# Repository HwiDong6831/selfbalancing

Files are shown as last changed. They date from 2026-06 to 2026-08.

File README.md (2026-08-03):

# 삼각형 셀프밸런싱 로봇

1축 밸런싱 휠을 통해 스스로 중심을 잡는 삼각형 로봇.

### 특징
외부 충격에 실시간으로 대응하여 균형을 유지.

가속도 센서를 3개 탑재하여, 센싱된 정보를 다수결로 결정하여 판단하도록 설계.

동작 영상 : https://www.youtube.com/shorts/YMNRPPPrXEo

## 목차

**계획 · 스펙**

1. [요구사항](#1-요구사항)
   - [기능 요구사항](#기능-요구사항)
   - [센서 결함 시뮬레이션 및 검증 계획](#센서-결함-시뮬레이션-및-검증-계획)
   - [디지털 트윈](#디지털-트윈)
2. [언어 / 빌드 환경](#2-언어--빌드-환경)
3. [라이브러리](#3-라이브러리)
4. [주요 부품](#4-주요-부품)

**구현**

5. [로봇 형상](#5-로봇-형상)
6. [서버 / 대시보드](#6-서버--대시보드)

## 1. 요구사항
### 기능 요구사항
- FR-1(센싱) : MPU6500 3개를 이용해 실시간으로 자세 정보를 측정해야 한다.
- FR-2(결함 허용) : Voting 알고리즘을 구현한다. 3개의 센서 데이터를 비교해 이상치를 배제한다.
- FR-3(균형 유지) : 정상 센서 데이터를 이용해 자세 정보를 계산하고, 상태피드백 제어(각도·각속도·휠속도)를 통해 로봇이 균형을 유지해야 한다.
- FR-4(모터 제어) : BLDC 모터를 FOC 방식으로 제어해야 한다.
- FR-5(모터 피드백) : MT6701을 ABZ 증분 방식으로 읽어 모터 정보를 실시간으로 측정해야 한다.
- FR-6(무선 통신) : Wi-Fi를 이용하여 센서 데이터를 확인하거나 로봇을 제어할 수 있어야 한다.
- FR-7(안정성) : 외부 충격이 발생하더라도 균형을 회복해야 한다.
- FR-8(디지털 트윈) : 모바일 웹에서 로봇의 현재 자세를 실시간 3D로 확인할 수 있어야 한다.

### 센서 결함 시뮬레이션 및 검증 계획

실제 하드웨어 고장을 기다리지 않고, 센서 데이터를 인위적으로 변조하여 결함 상황을 재현한다.

모바일에서 Wi-Fi 기반 제어로 구현한다.

1. 센싱 정보 누락

    특성 센서의 값을 무효 처리 한다.

    (하드웨어 고장, 통신 끊어짐 상황 묘사)

2. 값 고정 오류

    특정 센서의 값이 고정된 값이나, 마지막 정상 값을 유지되도록 한다.

    (register lock, 센서 freeze 상황 묘사)

3. 점진적 변형

    특성 센서의 값이 지속적으로 변형되도록 한다.

    (센서 열화, IMU drift 상황 묘사)

4. 다중 장애

    2개 센서에 1~3번 현상이 나타나도록 한다.

    (단일 센서 모드로 동작하는 상황 묘사)

### 디지털 트윈

모바일 웹에서 로봇의 현재 자세를 실시간 3D로 확인한다.

- 자세 소스: voting 통과 융합 기울기 + 엔코더 휠 각도.
- 표현: 기울기 1축과 휠 회전. 반작용휠 로봇이라 둘 다 같은 축으로 돌아, 휠을 몸통의 자식으로 두면 그대로 맞아떨어진다.
- 통신: WebSocket. ESP32 → Spring 서버 → 브라우저 중계.
- 렌더: 대시보드와 같은 Spring 서버가 호스팅(Three.js), 기존 프레임 `.obj` 를 `.glb` 로 변환해 사용.

상세: [docs/digital-twin.md](./docs/digital-twin.md)

## 2. 언어 / 빌드 환경

### 로봇 (ESP32)

| 항목 | 내용 |
|---|---|
| 언어 | C |
| 프레임워크 | ESP-IDF v5.5.4 |
| 빌드 | idf.py (CMake) |
| 타겟 보드 | ESP32 D1 Mini Live |

### 서버 / 대시보드

| 항목 | 내용 |
|---|---|
| 언어 | Java 21 |
| 프레임워크 | Spring Boot 4.1.0 (webmvc + websocket) |
| 빌드 | Gradle |
| 프론트 | HTML/CSS/JS, Three.js |

## 3. 라이브러리

| 기능 | 구현 |
|---|---|
| FOC 모터제어 | 직접 구현 — `esp/components/foc/` |
| 자기인코더(MT6701) | 직접 구현 — ESP32 PCNT로 ABZ 펄스 카운트, `esp/components/encoder/` |
| 가속도센서(MPU6500) | 직접 구현 — 멀티플렉서 경유 3채널, `esp/components/mpu6050/` |
| WebSocket 클라이언트 | `espressif/esp_websocket_client` |

## 4. 주요 부품
메인보드: ESP32 D1 Mini Live

FOC 드라이버: SimpleFOC Mini

멀티플렉서: PCA9548A

가속도센서: MPU6500

자기인코더: MT6701

모터: 2804-100KV 브러시리스

## 5. 로봇 형상

<table>
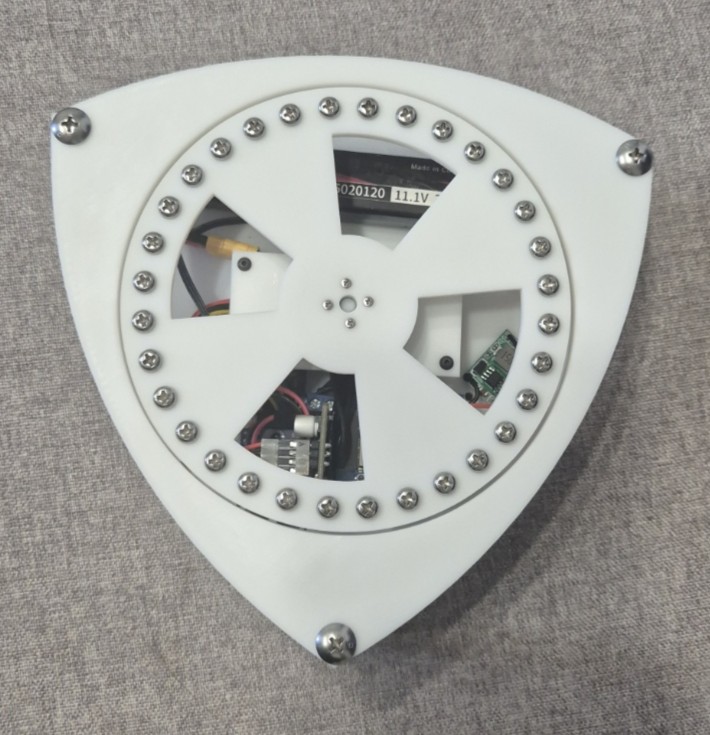
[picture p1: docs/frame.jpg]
로봇 형상 — 외부
  <tr><td></td></tr>
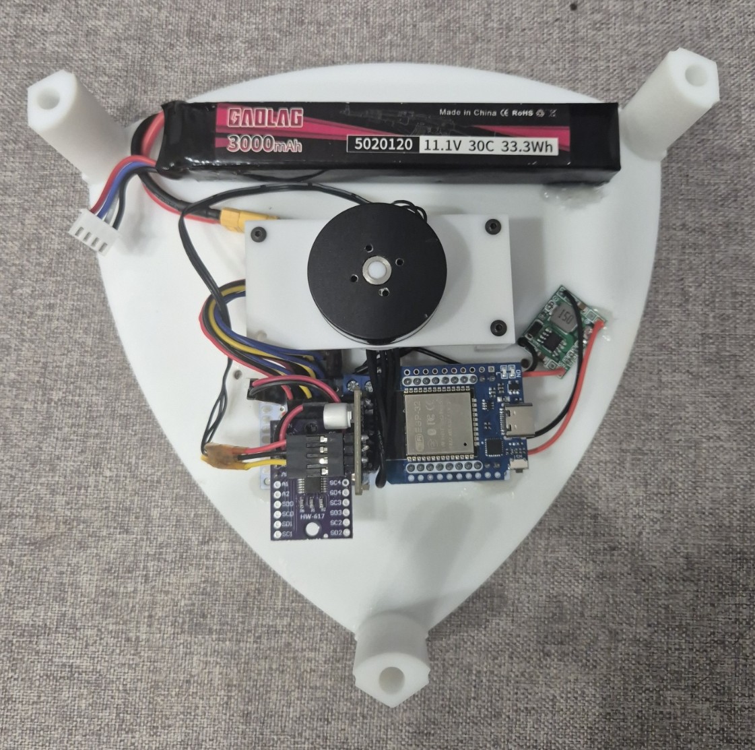
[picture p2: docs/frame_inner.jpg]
로봇 형상 — 내부
  <tr><td></td></tr>
</table>

## 6. 서버 / 대시보드

ESP32가 측정한 값을 브라우저에서 실시간으로 확인한다. ESP32를 웹서버로 쓰지 않고 **Spring 서버가 중계**한다.

```
ESP32 ──WS──► Spring 서버 ──WS──► 브라우저
              (중계 + 정적 호스팅)
```

대시보드 표시 항목:

- 밸런싱 상태 (기울기, 각속도, 기준 각도, q축 전압, 휠 각도)
- 센서 3개의 6축 값과 채널별 영점
- Voting 판정 — 가속도·자이로 각각의 채택/배제 채널
- 이상 이력 — 배제된 센서의 값, 채택 평균, 벌어진 폭을 표로 기록
- 3D 자세 — 실물 모델로 현재 기울기와 휠 회전을 실시간 표시
- ESP32 시리얼 로그 미러링

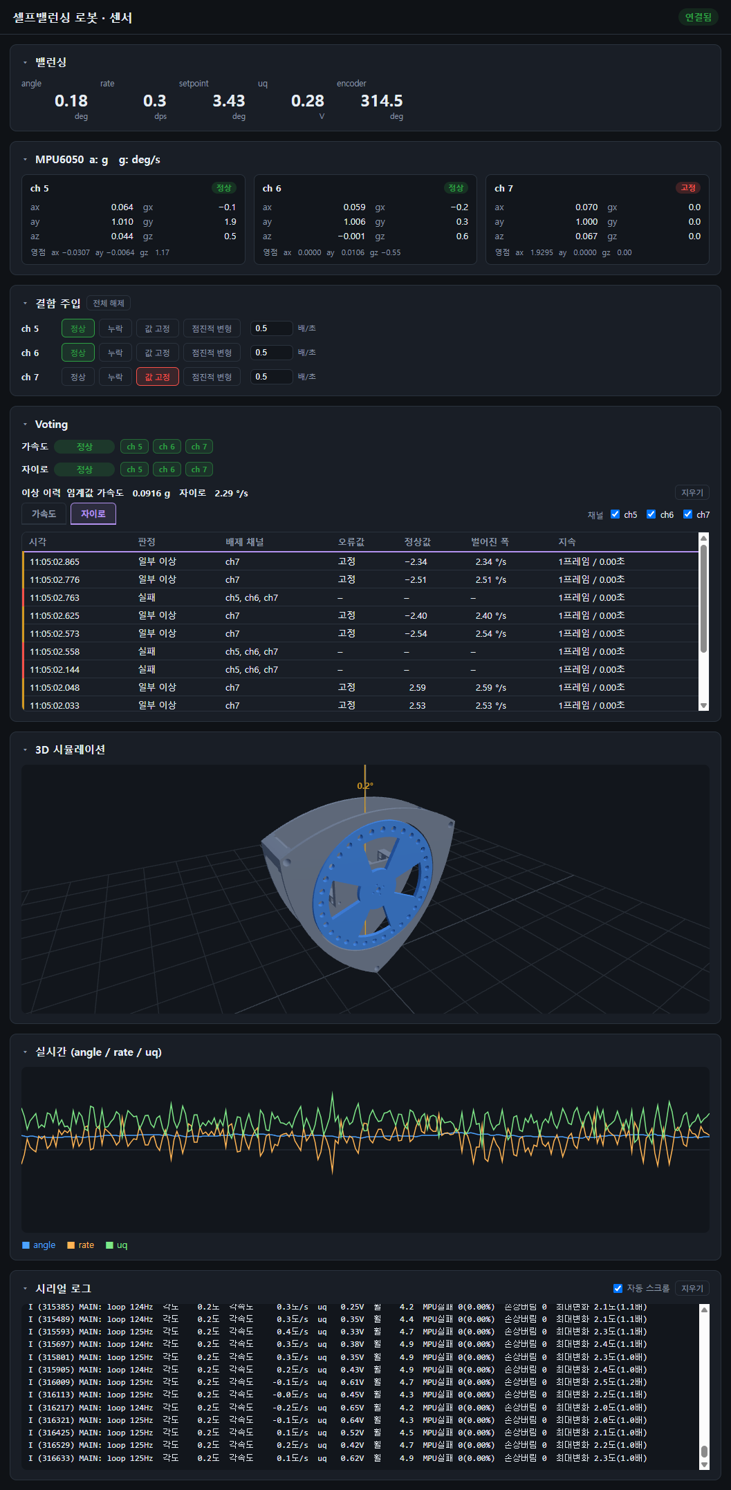
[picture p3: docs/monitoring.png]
대시보드


상세: [docs/server.md](./docs/server.md)

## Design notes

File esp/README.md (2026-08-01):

# esp — 밸런싱 로봇 펌웨어 (ESP-IDF v5.5)

ESP32 D1 Mini 에서 도는 제어 펌웨어. core 0 이 제어 루프, core 1 이 통신을 맡는다.

## 구조

```
main/           app_main. 초기화 → 캘리브레이션 → 1kHz 제어 루프
components/
  mpu6050/      MPU6500 ×3 (PCA9548A mux 0x70)
  encoder/      MT6701 자기 인코더 (0x06)
  foc/          전압모드 FOC (LEDC 3-PWM + EN)
  balance/      상보필터 각도 추정 + 토크모드 상태피드백
  telemetry/    WiFi STA + WebSocket 송신 + ESP_LOGx 미러링
```

## 빌드

`export.ps1` 이 py3.14 가상환경을 찾는데 실제 설치된 건 py3.11 이라 경로를 먼저 지정해야 한다.

```powershell
$env:IDF_PYTHON_ENV_PATH="C:\Espressif\python_env\idf5.5_py3.11_env"
. C:\Espressif\frameworks\esp-idf-v5.5.4\export.ps1

idf.py build
idf.py -p COM<n> flash monitor
```

WiFi/서버 주소는 커밋되지 않는다.
아래 명령어로 secrets.h 파일을 생성한 후, 내부에 로봇을 연결할 WiFi 및 서버 정보를 기입한다.
```
cp main/secrets.h.example main/secrets.h
```

## 주의

- 튜닝 중 통신을 완전히 배제하려면 `main.c` 의 `TELEMETRY_ENABLED` 를 0 으로 변경한다.

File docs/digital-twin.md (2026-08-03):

# 디지털 트윈

모바일 웹에서 로봇의 현재 자세를 실시간 3D로 확인하는 기능.

## 1. 목적

- 실제 기기의 자세를 모바일 화면의 3D 모델에 실시간 반영한다.
- 센서 결함 시뮬레이션 시 자세 변화를 시각적으로 검증하는 도구로 사용한다.
- 기존 모바일 Wi-Fi 제어 기능(FR-6)과 동일한 웹 UI에 통합한다.

## 2. 자세 데이터

### 자세 소스

- Voting 알고리즘을 통과한 융합 기울기.
- 엔코더가 읽은 휠 각도.

### 표현 방식 — 1축 기울기와 휠 회전

**측정 가능한 자유도가 1개다.** 물체가 향한 방향은 축 3개로 정해지는데, 중력은 "아래가 어디인가" 만 알려주므로 그중 둘까지만 고정된다. 나머지 하나(제자리 돌기)를 알려면 지자기 센서가 필요한데 이 로봇에는 없다. 자이로를 적분하면 몇 분 만에 오차가 쌓여 화면이 제멋대로 돌아간다.

그래서 쿼터니언을 쓰지 않는다. 쿼터니언은 세 축을 다 알 때 의미가 있고, 여기서는 채울 수 없는 성분을 지어내는 셈이 된다. 대신 **실제로 측정되는 기울기 1축과 휠 회전**을 보낸다.

반작용휠 로봇은 몸이 기우는 축과 휠이 도는 축이 같다. 그래서 3D 에서 휠을 몸통의 자식으로 두면 기울기는 휠이 저절로 따라오고, 휠 회전만 따로 주면 된다.

### 페이로드

- 기울기 `angle`, 휠 각도 `encoder.angle`. 텔레메트리 프레임에 이미 들어 있어 별도 필드가 필요 없다.
- 송신 주기: 50Hz.

## 3. 통신

- 프로토콜: **WebSocket** (저지연 연속 스트림, HTTP 폴링 대비 적합).
- 경로: **ESP32 → Spring 서버 → 브라우저**. ESP32 는 서버가 아니라 클라이언트다.
- 기존 모바일 제어 채널과 동일한 Wi-Fi 연결 재사용.

> 처음에는 ESP32 가 직접 WebSocket 서버가 되는 안이었으나, ESP32 부담과 동시 접속 수
> 때문에 Spring 서버가 중계하는 구조로 바꿨다. 근거는 [server.md](./server.md) 3장.

## 4. 모바일 3D 렌더

- 웹 기반 렌더링: **Three.js / WebGL**. 앱 설치 불필요.
- 웹 자산 호스팅: **대시보드와 같은 Spring 서버**. ESP32 온보드 flash 미사용.
- 3D 모델: 기존 프레임 export 재사용. `Assembly.obj`(몸통)와 `wheel.obj`(휠)를 각각 `.glb` 로 변환해 쓴다 — 둘이 따로 있어야 휠만 돌릴 수 있다.
- 몸통 그룹을 기울기만큼, 그 자식인 휠을 엔코더 각도만큼 회전시킨다.

## 5. 결함 시뮬레이션 연동

- 트윈 화면에 센서 상태 오버레이: 어느 센서가 faulted 인지, voting 결과 표시.
- 결함 주입 시 자세 흔들림을 3D로 시각 확인 → 검증 도구 역할.

## 6. 구성요소

| 계층 | 구성요소 |
|---|---|
| ESP32 | WebSocket 클라이언트 (`espressif/esp_websocket_client`) |
| 자세 소스 | voting 통과 융합 기울기 + 엔코더 휠 각도 |
| 서버 | Spring Boot — 중계 + 웹 자산(HTML/JS) 호스팅 |
| 모바일 웹 | Three.js 3D 렌더, WebSocket 클라이언트 |
| 3D 모델 | 프레임 export 를 변환한 `.glb` (몸통 / 휠) |

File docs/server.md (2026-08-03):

# 센서 웹 서버 구조와 선택 근거

로봇의 센서 정보를 웹 페이지에서 실시간으로 보기 위한 별도 서버(`server/`)의 설계 결정을 정리한다. **무엇을 했는지보다 왜 그렇게 했는지**에 초점을 둔다.

## 1. 목적

- ESP32가 측정한 센서/제어 상태를 브라우저에 실시간 스트리밍한다.
- 결함 시뮬레이션(FR-2)·디지털 트윈(FR-8)의 공통 표시 기반으로 쓴다.
- 현재 단계: **ESP32 연동 전에 서버·웹을 먼저 완성**하고, 가짜 데이터로 검증한다.

## 2. 스택

| 항목 | 선택 |
|---|---|
| 언어/런타임 | Java 21 (Temurin) |
| 프레임워크 | Spring Boot 4.1.0 (webmvc + websocket) |
| 빌드 | Gradle |
| 직렬화 | Jackson 3 (`tools.jackson`, Spring Boot 4 기본) |
| 프론트 | 순수 HTML/CSS/JS, 정적 호스팅 (라이브러리 무의존) |

## 3. 아키텍처 선택 — Spring 허브

```
ESP32 ──WS──► Spring 서버 ──WS──► 브라우저
                    (중계 + 정적 호스팅)
```

두 가지 후보가 있었다.

- **(A) Spring 허브 (채택):** ESP32가 Spring으로 데이터를 보내고, Spring이 브라우저로 중계 + 웹 자산 호스팅.
- **(B) ESP32 직결:** ESP32가 직접 WebSocket 서버가 되고 브라우저가 붙음 (초기 `digital-twin.md` 안).

**(A)를 택한 이유:**

- ESP32 부담을 줄인다. 온보드 flash에 웹 자산을 안 올려도 되고, 동시 접속 수 제한(임베디드 WS 서버)에서 자유롭다.
- 다중 브라우저(PC + 모바일 동시)를 서버가 fan-out으로 감당한다.
- 로깅·기록·결함 주입 제어 등 확장 지점을 서버에 둘 수 있다.
- Spring Boot 스캐폴드에 이미 websocket starter가 포함돼 있어 자연스럽다.

## 4. 핵심 설계 — `TelemetrySink` 경계(seam)

데이터를 **만드는 쪽**과 **뿌리는 쪽**을 인터페이스 하나로 갈라 놓았다.

```java
public interface TelemetrySink {
    void publish(SensorFrame frame);
}
```

- **생산자**(현재 `DummyTelemetrySource`)는 이 인터페이스에만 의존한다. 뒤에서 WebSocket으로 어떻게 전송되는지 전혀 모른다.
- **구현체**(`DashboardWebSocketHandler`)가 받은 프레임을 접속한 모든 브라우저로 broadcast 한다.

**이 벽을 세운 이유 — 생산자 교체 비용을 0으로 만들기 위해서.** 지금은 더미가 `publish`를 부르고, ESP32 연동 시엔 ingest 핸들러가 같은 `publish`를 부른다. 그 사이 **전송·스키마·프론트 코드는 한 줄도 바뀌지 않는다**.

## 5. 데이터 계약 — `SensorFrame`

서버↔브라우저가 합의하는 JSON 한 프레임의 모양을 `record` 하나로 고정했다.

- `ts`, `sensors[3]`(MPU 6축 + fault), `voting`(used/rejected), `balance`(angle/rate/setpoint/uq), `encoder`.
- `balance` 필드는 펌웨어 `main.c` 변수와 1:1 대응.
- **계약을 한 곳에 못박은 이유:** 생산자·소비자·프론트가 각자 이 record 하나만 보고 맞추면 되므로, 필드 변경 시 파급 지점이 명확하다.

## 6. 더미 우선(mock-first) 전략

- `DummyTelemetrySource`가 `@Scheduled(fixedRate=33)`로 ≈30Hz 프레임을 생성해 `publish`.
- 값은 −10~10 **삼각파** 하나(`v`)를 모든 필드에 채우는 단순 형태. *실제처럼 보일 필요가 없으므로* 사인파·노이즈·센서 스케일 흉내를 걷어내고 최소화했다.
- `@ConditionalOnProperty(telemetry.mock.enabled)`로 켜고 끈다. **ESP32 연동 시 `false`로 두면 더미 빈이 아예 생성되지 않는다** — 코드 삭제 불필요.

**mock-first 이유:** 무선 펌웨어가 나오기 전에 서버·웹 전체 경로를 먼저 눈으로 검증하기 위해서.

## 7. 통신 — WebSocket + 순수 fan-out

- 프로토콜: **WebSocket** (저지연 연속 스트림, HTTP 폴링 대비 적합).
- 엔드포인트: `/ws/telemetry`.
- STOMP 같은 pub/sub 계층 없이 **순수 `TextMessage` fan-out**을 택했다. 채널이 하나(텔레메트리 단방향 브로드캐스트)뿐이라 STOMP는 오버킬.

## 8. 프론트엔드 — 무의존 정적 웹

- Spring이 `static/`을 자동 서빙. 앱 설치 불필요, 모바일 접속 가능.
- 차트는 외부 라이브러리 없이 `<canvas>`에 직접 그린다(최근 240프레임 링버퍼). CSP·오프라인·파일 수 측면에서 유리.
- 데이터 수신(30Hz)과 화면 렌더(`requestAnimationFrame`)를 분리해 부드럽게 그린다.
- 숫자 표시는 고정폭 + 부호 자리 확보(음수 `−`, 양수 figure space)로 값이 바뀌어도 흔들리지 않게 했다.

## 9. 동시성(스레드) 결정

서버는 멀티스레드다. 스케줄러 스레드(더미 생산)와 톰캣 연결 스레드(브라우저 접속/해제)가 공유 상태를 건드린다. 판단 기준은 **"이 데이터를 건드리는 스레드가 2명 이상인가"**.

| 대상 | 스레드 수 | 처리 | 이유 |
|---|---|---|---|
| `sessions` 집합 | 스케줄러 + 톰캣 다수 | `CopyOnWriteArraySet` | 순회(30Hz)가 잦고 변경(접속)이 드문 비대칭. 순회 중 변경돼도 예외·손상 없음 |
| 한 세션 전송 | 현재 1, 미래 다수 | `synchronized(session)` | `WebSocketSession.sendMessage`는 동시 호출에 안전하지 않음. 세션 단위로만 직렬화 |
| `v`, `dir` (더미) | 실질 1 (단일 스케줄러 풀) | 없음 | 겹쳐 실행되지 않아 경쟁 상태 없음. 불필요한 동기화 배제 |

`synchronized(session)`은 현재 생산자가 하나뿐이라 당장은 불필요하지만, ESP32 소스가 별도 스레드로 붙는 미래를 대비해 미리 건다(비용이 거의 없고, 누락 시 재현이 어려운 버그).

## 10. ESP32 연동 시 변경점 (설계의 결실)

1. `EspIngestHandler`(WebSocket ingest) 신설 → 받은 JSON을 `SensorFrame`으로 파싱 후 **동일한 `sink.publish(frame)`** 호출.
2. `application.properties`에서 `telemetry.mock.enabled=false`.

→ `DashboardWebSocketHandler`, `SensorFrame`, 프론트는 **불변**. 생산자만 교체.

## 11. 실행

```
JAVA_HOME = <Temurin 21 경로>
./gradlew.bat bootRun   →   http://localhost:8080
```

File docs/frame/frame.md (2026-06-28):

FreeCAD로 모델링
3D프린팅 대행 업체 이용
인서트 없이 볼트와 너트로 고정

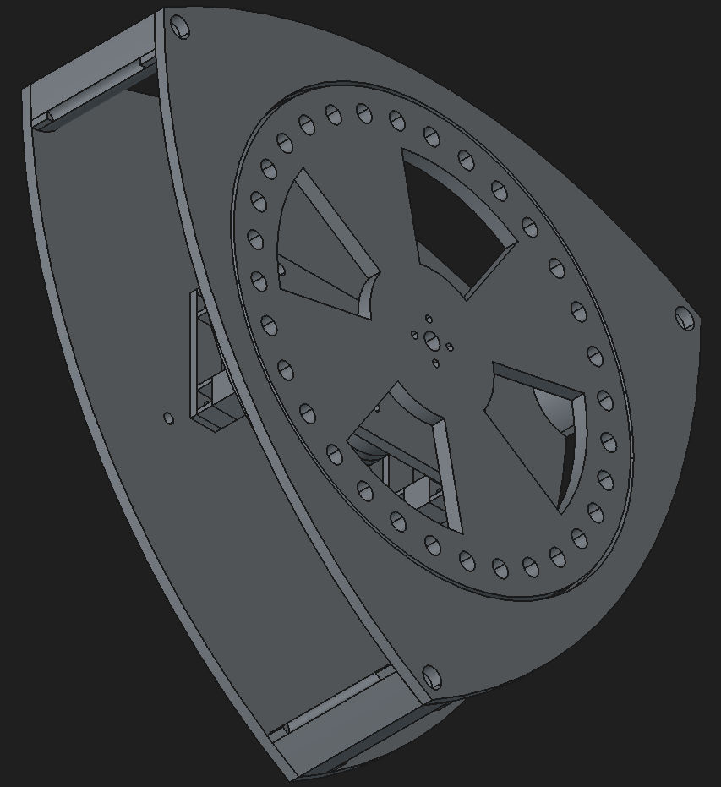
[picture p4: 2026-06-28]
docs/frame/frame.png

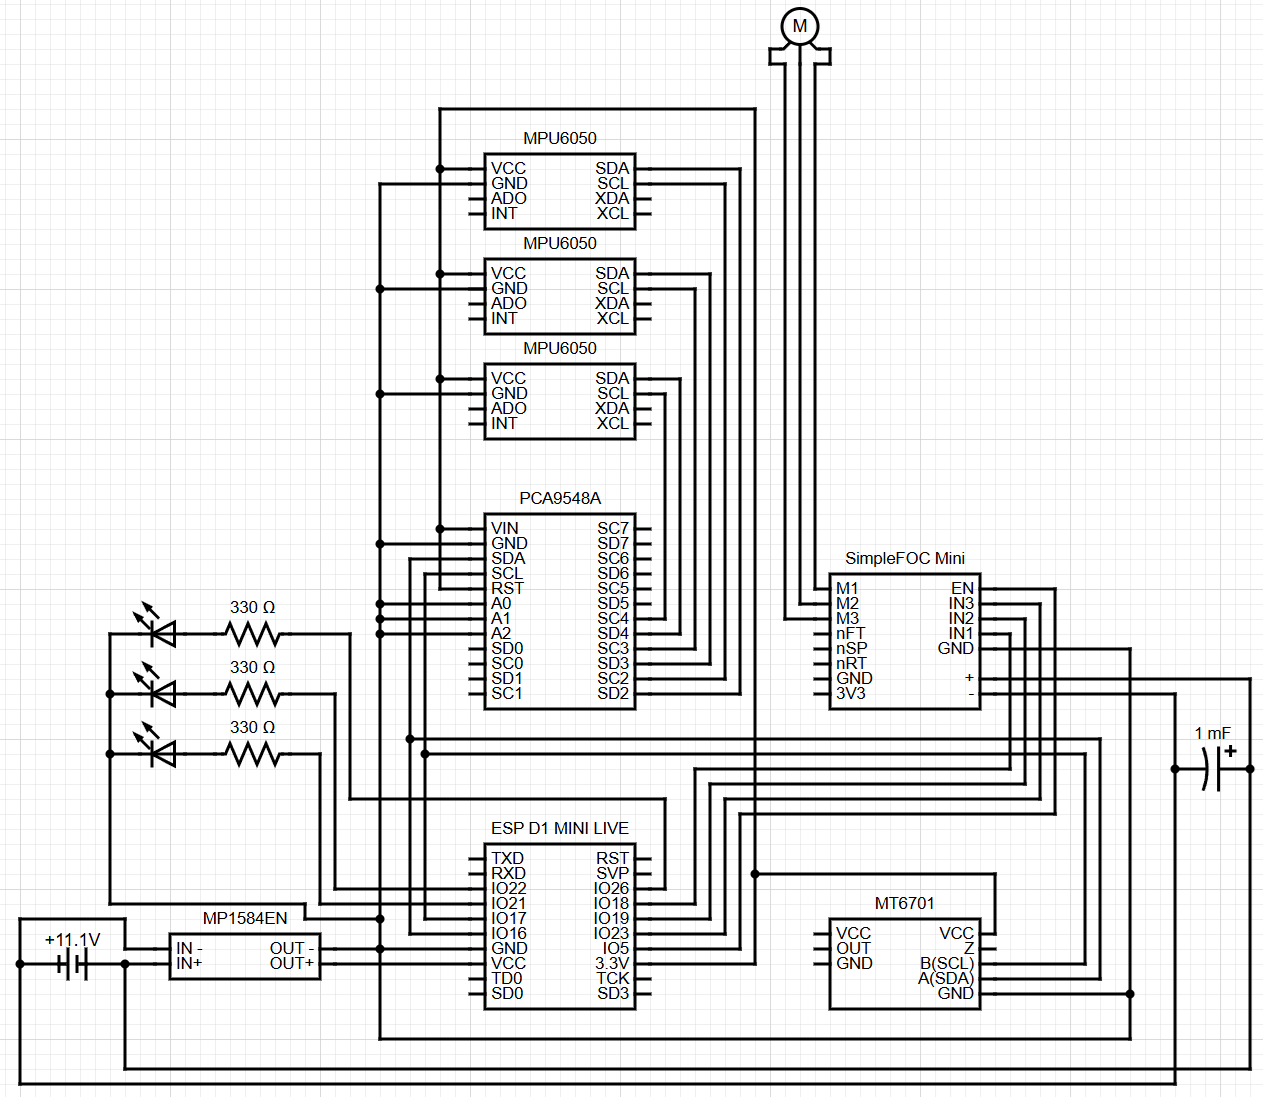
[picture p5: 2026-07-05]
docs/circuit/circuit.png

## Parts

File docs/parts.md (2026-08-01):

# 부품 선정

삼각형 1축 셀프밸런싱 로봇 부품 목록 및 선정 근거.

## 부품 목록

| 분류 | 부품 | 수량 |
|---|---|---|
| 메인보드 | ESP32 D1 Mini Live | 1 |
| FOC 드라이버 | SimpleFOC Mini | 1 |
| 멀티플렉서 | PCA9548A | 1 |
| 가속도센서 | MPU6500 | 3 |
| 자기인코더 | MT6701 | 1 |
| 전압 스텝다운 | MP1584 | 1 |
| 모터 | 2804-100KV 브러시리스 | 1 |
| 배터리 | 3S Lipo 3000mAh | 1 |
| 기판 | 단면 만능기판 7x9cm 2.54mm | 1 |

### RLC / 기타
- 세라믹 커패시터 0.1uF 50V
- 전해 커패시터 1000uF 25V

## 선정 근거

### 메인보드 — ESP32 D1 Mini Live
- 센서/제어/통신 태스크 분리를 위해 듀얼코어 필요
- FreeRTOS 내장
- WiFi/BLE 내장(정확한 자세 제어를 위해 무선으로 제어)

### FOC 드라이버 — SimpleFOC Mini
- 3상 BLDC 구동용. 처음엔 SimpleFOC 라이브러리를 쓰려고 골랐으나,
  지금은 보드만 쓰고 FOC 제어는 라이브러리 없이 직접 구현했다.

### 멀티플렉서 — PCA9548A
- I2C 주소 충돌 해결을 위해 사용.
- 가속도센서를 3개 사용하기 위함.(기존엔 할당 가능한 주소가 부족함)

### 가속도센서 — MPU6500 x3
- 로봇 자세 측정용.
- 결함 내성을 위해 3개 사용.
- 모듈에는 "MPU6050" 으로 인쇄되어 있으나 `WHO_AM_I` 가 `0x70` 을 반환함. 실제 칩은
  **MPU6500** 임(6050 이면 0x68). 레지스터 맵이 호환돼 동작에는 문제가 없음.

### 자기인코더 — MT6701
- 모터 각도 측정용

### 전압 스텝다운 — MP1584
- 배터리(11 ~ 12.6V) → ESP32·센서(3.3V) 전압 강하용

### 모터 — 2804-100KV 브러시리스
- 밸런싱 휠 동작을 위해 고토크 모터 사용(100KV)

### 배터리 — 3S Lipo 3000mAh
- 모터 정격 전압/전류에 맞춤.
- 밸런싱 순간 토크(피크 전류) 대응.
- 500mAh로 충분하나, 테스트/튜닝 반복을 위해 고용량 선택

### RLC / 기타
- **세라믹 0.1uF:** 고주파 노이즈 제거
- **전해 1000uF:** 모터 피크 전류 시 전압 강하 방어

### 프레임
- 9600 레진 재질로 3D프린팅하여 조립
- 실내 사용, 프로토타입 검증 목적, 비용을 고려했을 때 적합한 재질이라고 판단함

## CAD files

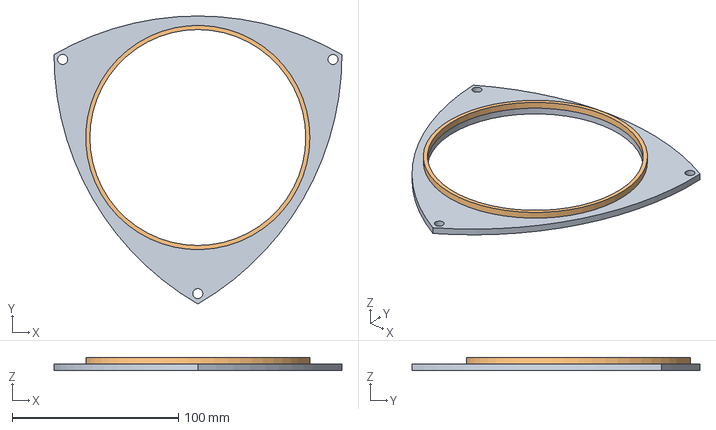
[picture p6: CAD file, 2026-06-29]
docs/frame/front.FCStd
173.4 x 173.4 x 8.00 mm
몸통
몸통003

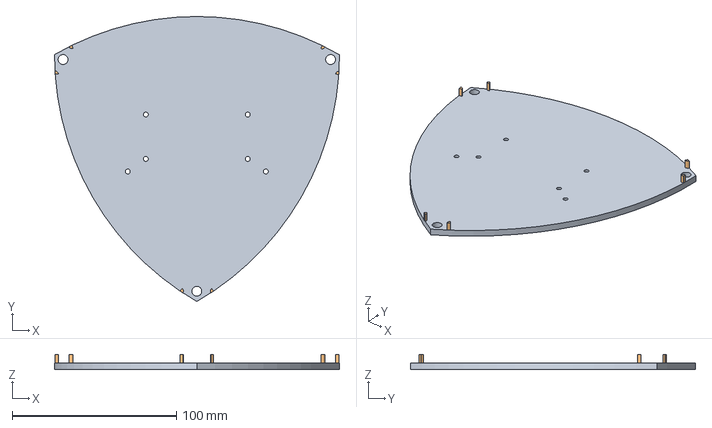
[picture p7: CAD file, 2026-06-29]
docs/frame/back.FCStd
173.4 x 173.4 x 9.00 mm
몸통
몸통002

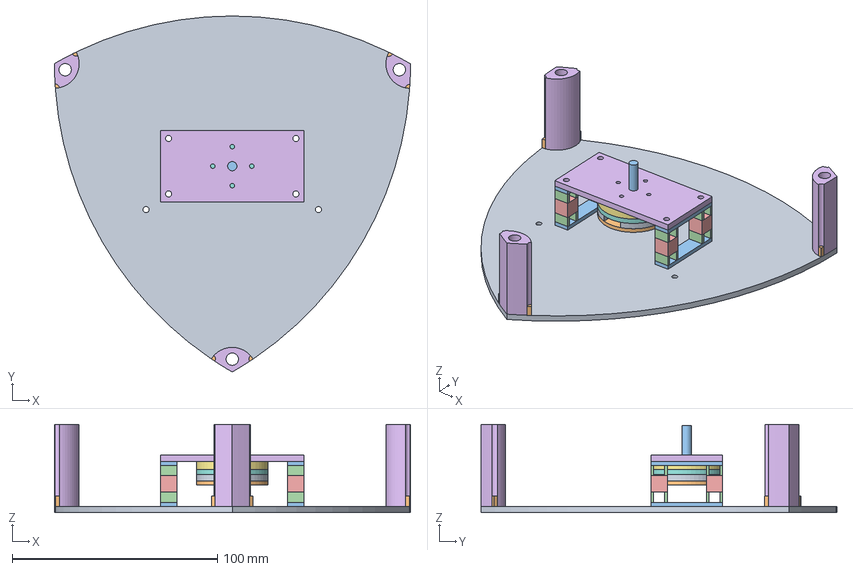
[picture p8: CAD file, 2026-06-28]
docs/frame/종합.FCStd
173.4 x 173.4 x 43.0 mm
몸통001
몸통003
몸통007 x 2
몸통015 x 2
몸통008
몸통016
몸통017
몸통011
몸통010
몸통009
몸통006
몸통005
몸통004
몸통002

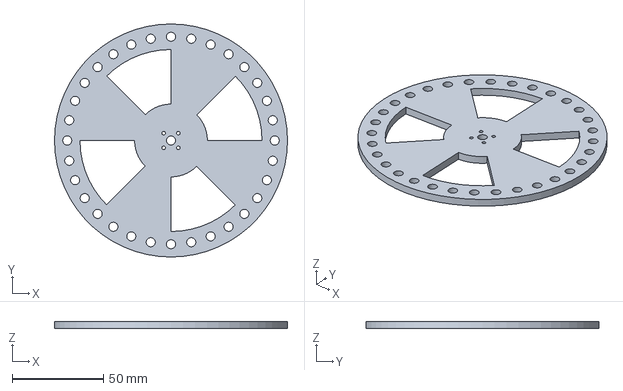
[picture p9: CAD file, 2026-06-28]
docs/frame/wheel.FCStd
128.0 x 128.0 x 4.00 mm

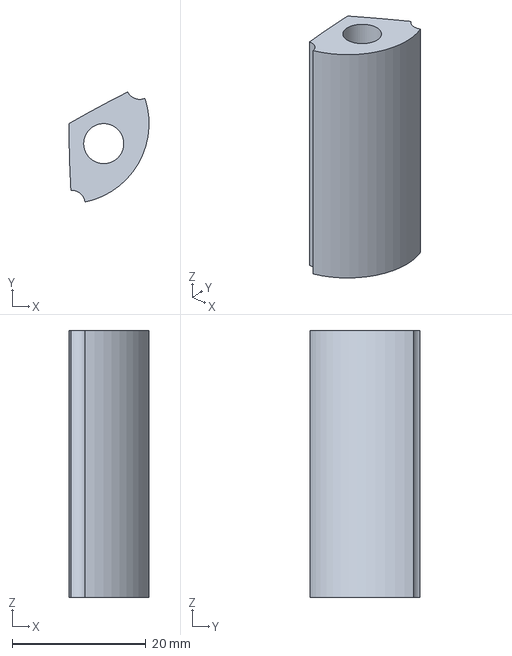
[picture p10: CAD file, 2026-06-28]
docs/frame/spacer.FCStd
12.0 x 16.5 x 40.0 mm

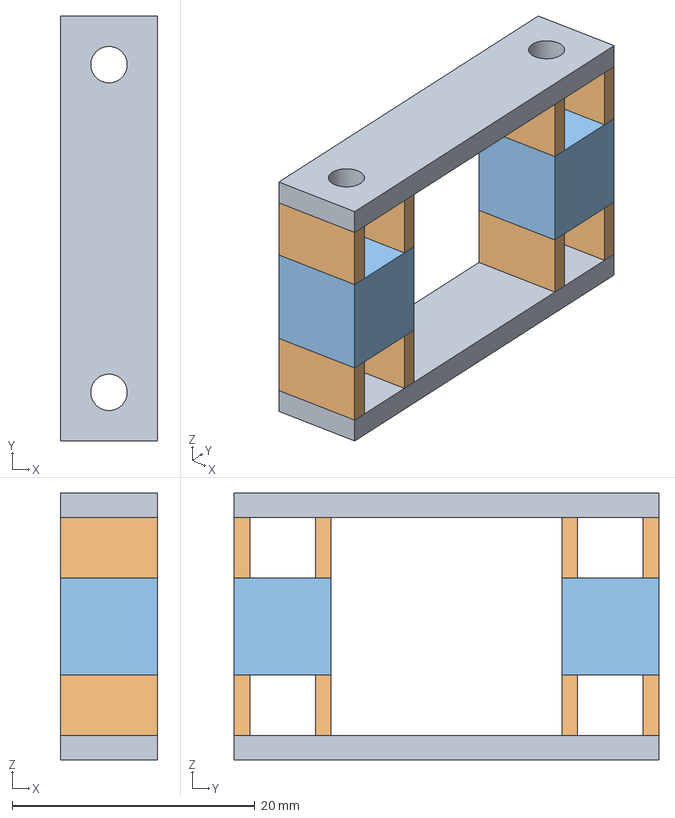
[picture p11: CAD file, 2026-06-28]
docs/frame/motorSpacer.FCStd
8.00 x 35.0 x 22.0 mm
몸통007 x 2
몸통 x 2
몸통008

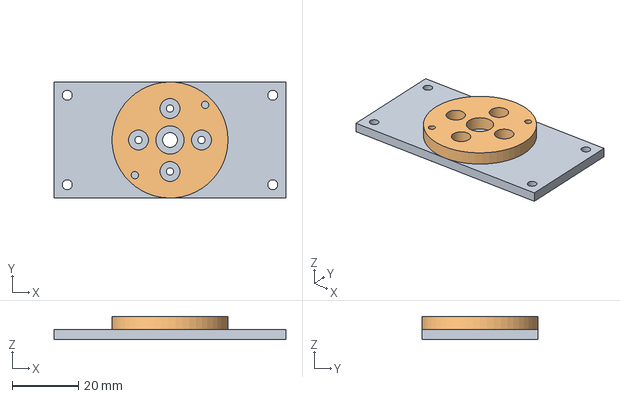
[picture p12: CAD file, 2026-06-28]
docs/frame/motorHolder.FCStd
70.0 x 35.0 x 7.00 mm
몸통002
몸통003

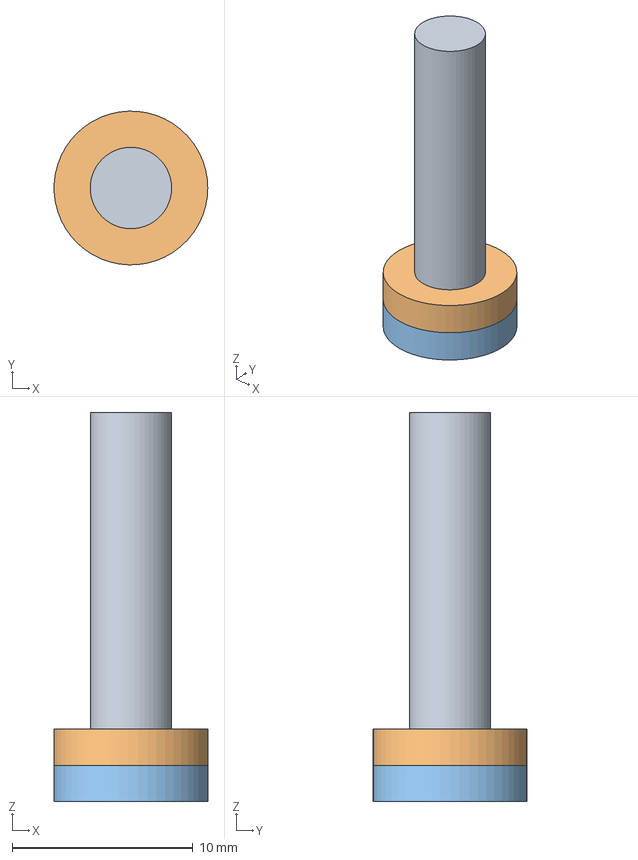
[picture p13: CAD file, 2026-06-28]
docs/frame/magnetHolder.FCStd
8.49 x 8.50 x 21.5 mm
몸통006
몸통005
몸통004

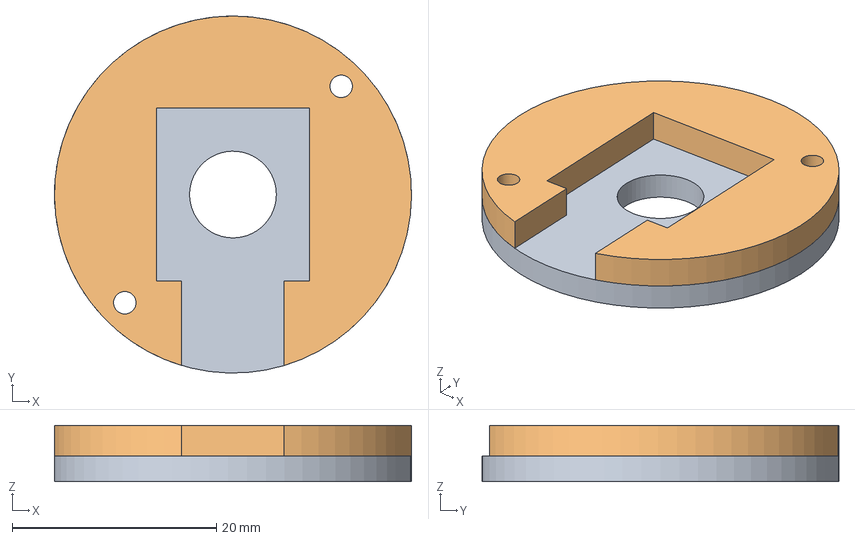
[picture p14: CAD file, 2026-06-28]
docs/frame/encoderHolder_1.FCStd
35.0 x 35.0 x 5.50 mm
몸통011
몸통010

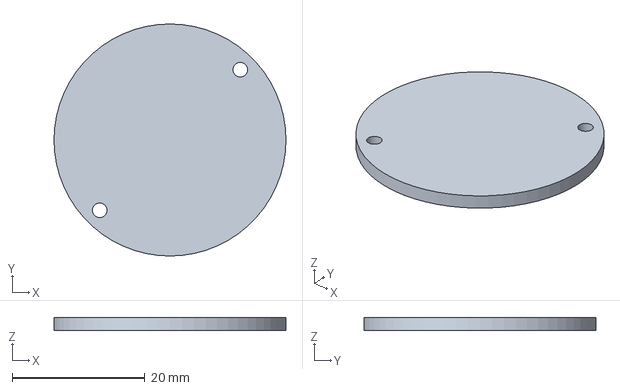
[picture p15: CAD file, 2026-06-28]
docs/frame/encoderHolder_2.FCStd
35.0 x 35.0 x 2.00 mm

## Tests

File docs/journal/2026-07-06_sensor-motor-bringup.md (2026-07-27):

# 작업 일지 - 2026-07-06 : 센서·엔코더·모터 브링업

삼각형 셀프밸런싱 로봇의 핵심 부품(IMU 3개, 마그네틱 엔코더, BLDC 모터+드라이버)을
ESP32(wemos_d1_mini32)에 하나씩 연결하며 인식·동작을 검증한 기록.

## 목표

- TCA9548A 멀티플렉서 경유 MPU6050 3개 가속도 읽기
- MT6701 마그네틱 엔코더(I2C) 각도 읽기
- SimpleFOC Mini 드라이버 + BLDC 모터 회전 검증

## 하드웨어 구성 / 배선 (검증 완료)

### I2C 버스 (공유)
- ESP32 **SDA=GPIO16, SCL=GPIO17** (`Wire.begin(16, 17)`) — 기본 21/22 아님, 주의
- 버스 속도 400kHz

| 장치 | 주소 | 연결 |
|---|---|---|
| TCA9548A 멀티플렉서 | 0x70 | A0/A1/A2 = GND (현재 미연결, floating 상태로도 0x70 잡힘) |
| MPU6050 ×3 | 0x68 | mux 채널 **0, 1, 6** 의 SDn/SCn. 각 AD0=GND |
| MT6701 엔코더 | 0x06 | 메인 버스 직결 (mux 안 거침). **IIC 솔더 점퍼 납땜 필수** |

### 왜 멀티플렉서가 필요한가

ESP32 에는 I2C 컨트롤러(버스)가 **2개** 있고, 컨트롤러마다 7비트 주소 0x00~0x7F(128개)를
다룬다. 그중 0x00~0x07 과 0x78~0x7F 는 예약이라 실제로 쓸 수 있는 건 **0x08~0x77(112개)**.

MPU6050 이 2개였다면 컨트롤러 하나씩 나눠 주소 충돌을 피할 수 있다.
**3개라서 안 된다.** 그래서 mux 로 채널을 갈라 붙인다.

mux 는 여러 입력 중 하나를 골라 출력에 연결하는 스위치다. 대가가 있다:

- 폴링 주기가 짧을수록 **채널 전환 오버헤드**의 비중이 커진다
- 여러 채널과 **동시 통신 불가** — 순차 접근해야 한다

### ESP-IDF I2C API 패턴

`_config_t` = 장치·버스를 만들기 위한 설정 구조체, `_handle_t` = 만들어진 객체(식별자).
ESP-IDF 페리페럴 API 전반이 같은 꼴이다.

```c
i2c_device_config_t cfg = { ... };            // 1. 설정을 채우고
i2c_master_dev_handle_t dev;                  // 2. 핸들(빈 손잡이)을 준비
i2c_master_bus_add_device(bus, &cfg, &dev);   // 3. 설정을 넣으면 핸들이 나온다
i2c_master_transmit(dev, ...);                // 4. 이후엔 핸들로 "이 장치"를 지목
```

> 이 프로젝트는 이후 `i2c_master` 를 버리고 레거시 `driver/i2c.h` 로 이관했다.
> 이유는 [2026-07-21 일지](2026-07-21_i2c-bus-hang.md) 참조.

### SimpleFOC Mini (3-PWM 드라이버)
- EN=GPIO5, IN1=GPIO18, IN2=GPIO19, IN3=GPIO23
- 모터 3상 → M1/M2/M3
- 드라이버 전원(VM) → 3S Lipo (~11.3V 실측), GND 공통 필수

## 시행착오 기록 (중요)

### 1. I2C 핀이 기본값 아님 (21/22 → 16/17)
- 증상: `mux NO ACK`, 메인 버스 스캔 `(none)`, 모든 장치 미검출
- 원인: 실제 배선은 GPIO16/17인데 `Wire.begin()` 기본값(21/22) 사용
- 해결: `Wire.begin(16, 17)` 명시

### 2. WHO_AM_I = 0x70 — 클론이 아니라 애초에 MPU6500
- 증상: 채널 스캔에 0x68 뜨는데(장치 존재) `mpuInit()` FAIL
- 원인: 코드가 WHO_AM_I 0x68/0x69만 허용. 이 칩은 **0x70** 반환
- 해결: WHO_AM_I 체크 완화 — 통신 실패(0x00/0xFF)만 거르고 나머지 응답 통과
- 데이터 자체는 정상 (정지 시 az ≈ +1.00g 확인)
- **정정(2026-07-27)**: 처음엔 "MPU6050 클론칩의 특성" 으로 적었으나 틀렸다.
  **0x70 은 MPU6500 의 WHO_AM_I 값이다.** GY-521 계열 모듈이 MPU6050 이름으로 팔리면서
  실제로는 MPU6500/9250 이 올라간 경우가 흔하다. 쓰는 레지스터(가속도·자이로 14바이트
  버스트, `PWR_MGMT_1`)는 두 칩이 같아 동작에는 문제가 없다. 표기만 틀린 것

### 3. MT6701 기본 SSI 모드 → 버스 hang
- 증상: MT6701을 I2C 버스에 추가한 뒤 **전체 버스 마비**
  - SDA/SCL idle 1.7V (정상 3.3V), 모든 주소 `I2C hardware timeout`
  - VCC 3.3V 정상, SDA-SCL 단락 아님
- 원인: 이 MT6701 모듈은 **기본 SSI 모드**. 보드에 `IIC ->` 표기 + 솔더 점퍼 패드 2개.
  점퍼 미납땜 상태로 SDA/SCL에 물리면 칩이 SSI로 동작하며 라인을 당겨 버스 hang
- 해결: **`IIC ->` 솔더 점퍼 2개 납땜(브릿지)** → I2C 모드 활성화 → 정상
- 판별법: 문제 장치만 떼고 스캔해서 버스 살아나는지 확인

### 4. USB 연결 끊김 (코드 43 / Write timeout)
- 증상: 업로드 시 `A serial exception error: Write timeout`, 장치관리자 "알 수 없는 USB 장치(장치 설명자 요청 실패) 코드 43"
- 관찰: esptool이 COM5로 자동인식했으나 `pio device list` 상 COM5는 **Sony 장치(VID 054C)** — ESP32 아님. 진짜 ESP32 포트가 목록에 없었음
- 원인: USB 데이터 연결 불안정 (케이블/커넥터/노이즈). 전원 LED는 켜져도 데이터선 불량이면 이 증상
- 참고: ESP32 USB-시리얼 칩 VID = `10C4`(CP210x) 또는 `1A86`(CH340)
- 해결: 재연결 후 정상화 (케이블/포트 확인)

### 5. SimpleFOC BLDCMotor 오픈루프가 PWM 0 출력 (미해결, 우회)
- 증상: `motor.controller = velocity_openloop` + `motor.move()` 호출 시 IN1/2/3 전부 0V, 모터 무반응
  - `driver.init()` 성공, `MOT:Enable driver` 로그 정상, `motor.enable()` 추가해도 동일
- 격리 검증:
  - **`driver.setPwm(8,4,1)` 직접 호출은 정상** — IN1/IN2/IN3 = 2.2V/1.1V/0.27V (8:4:1 비율) → 드라이버·모터·PWM 하드웨어 전부 정상
  - 즉 SimpleFOC `BLDCMotor` 오픈루프 레이어만 0 출력
- 우회: motor 객체 버리고 **오픈루프 직접 구현** (전기각 sweep + SPWM을 `driver.setPwm`으로) → 모터 정상 회전
- TODO: 원인 규명 필요. FOC 클로즈드루프(`initFOC()`)는 경로가 다르므로 될 가능성 있음. 안 되면 재조사

## 최종 검증 결과

- ✅ MPU6050 ×3 (채널 0/1/6) 가속도 정상 (정지 az ≈ +1.00g)
- ✅ MT6701 각도 정상 (축 회전 시 0~360° 매끄럽게 변화)
- ✅ 드라이버 + 모터 회전 정상 (오픈루프 직접 구현으로 확인)

## 특이사항 / 주의

- **오픈루프는 발열 큼** — 회전자 위치 무시하고 전압 강제 인가 → 무효전류. 저속·정지 시 심함.
  검증용으로만 짧게. 전압 낮게(1~2V). FOC 가면 발열 급감
- MT6701 `IIC ->` 점퍼 납땜 안 하면 I2C 버스 전체가 죽으니 재조립 시 반드시 확인

## 다음 작업 (TODO)

1. FOC 클로즈드루프: MT6701 + 모터 정렬(`initFOC`), 위치/속도 제어
   - SimpleFOC `MagneticSensorI2C`로 MT6701(0x06, 14bit, reg 0x03/0x04) 설정
2. BLDCMotor 오픈루프 0V 원인 규명 (시행착오 #5)
3. 모터 pole pairs 확정 (현재 코드 임시값 7)
4. mux A0/A1/A2 → GND 확정 연결 (현재 floating)
5. 3개 IMU 융합 → 기울기 추정 → 밸런싱 제어 루프

## 코드 상태

- `src/main.cpp` : 현재 오픈루프 직접 구현(모터 검증용). 이전 단계 코드(MPU/MT6701 읽기)는
  순차적으로 덮어써짐 — 필요 시 이 일지의 배선/설정 참고해 복원
- `src/pins.h`, `src/mpu6050.h` : env 분리 시도 때 만든 헬퍼. 현재 main.cpp 미참조(orphan).
  핀·주소·MPU 헬퍼 참고용으로 남겨둠

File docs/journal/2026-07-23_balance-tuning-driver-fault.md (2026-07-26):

# 2026-07-23 : 밸런싱 튜닝 진행 + 모터 출력 상실

토크모드 밸런싱을 튜닝하던 중 모터 출력이 사라져 중단. 당시엔 드라이버 고장으로 판단했으나
**후속 확인 결과 원인은 배터리 전압 저하였다.** 아래 §후속 확인 참조.

---

## 진행 상황 (동작 검증됨, 전부 커밋)
- FOC 정렬 d축 교정 + 인코더 버스트 → 커뮤테이션 정상
- 자이로 + 상보필터 각도 추정 (똑바로=0, wrap 제거)
- 토크모드 상태피드백 `uq = K1·angle + K2·rate`
- 밸런스 setpoint 캘리브레이션 (시작 시 밸런스 자세 잡고 2초 → 그 각도를 0 기준)
- 각도 데드밴드 (±1°)

## 튜닝 상태 (미완)
- **중앙에 두면 ~1초 균형 유지하나, 혼자서 넘어짐** → 안정성/튜닝 문제 (모멘텀 한계 아님).
- 게인 K1=-2.0, K2=-0.2 까지 올림. 여전히 발산.
- 미검토: 데드밴드가 오히려 무복원 데드존→드리프트 유발 가능(DEADBAND 0 테스트 필요), setpoint 정밀도, 적분항.

## 실패한 실험: 디커플링 (기록)
- 가설: 복원 시 "턱 넘어감"이 커뮤테이션 275Hz 한계 때문.
- 시도: FOC 커뮤테이션(인코더+토크) 매 iter, MPU/밸런싱 5 iter마다 → ~670Hz.
- 결과: **복원 개선 0 + 새 소음(시이익)** → 되돌림.
- 교훈: 벽은 커뮤테이션 속도 아님. 그리고 **공유 I2C 버스에선 인코더 고속 읽기가 mux/MPU와 경합**해 고속 커뮤테이션 자체가 어려움(인코더가 SPI/ABZ 등 I2C 밖이어야 가능 = 하드웨어).

---

## 모터 출력 상실 (사실 기록)

> 이 절은 **당시 관측·판단을 그대로 남긴 것**이다. 결론은 §후속 확인 에서 뒤집혔다.

### 증상 (관측된 사실, 순서대로)
1. 튜닝 중 모터 토크 점점 약해짐 + "쉬이익" 소음.
2. 전원 OFF 후 손회전: 매끄러움. 모터 발열 없음(만졌을 때 안 뜨거움).
3. 구동(오픈루프): 조금 돌다 멈춰 진동. **커맨드 속도와 무관하게 동일.**
4. 정적 벡터 홀드(ud=6V, 전기각 0)에서 3상 출력 DC 전압 측정:
   - 시작 **3.6 / 3.5 / 3.5 V** → 한 상이 점점 감소해 0 → **셋 다 0V**.
   - 이 과정에서 소음 점점 작아지다 멈춤, 모터 정지.
5. 최종 상태: 3상 출력 전부 **0V**, 모터 무동작·무음.

### 측정으로 확인된 부품 상태
| 부품 | 상태 | 측정 근거 |
|---|---|---|
| 모터 | 정상 | 3상 저항 3쌍 모두 20Ω(균등), 손회전 역기전력 3쌍 균등 발전 |
| 배선 | 정상 | 3상 도통 OK |
| ESP32 | 정상 | 코드 계속 실행됨 |
| 드라이버(SimpleFOC Mini) | 출력 없음 | 3상 출력 전부 0V, 스위칭 안 됨 |

→ **당시 결론: 드라이버가 3상 출력을 상실.** (오판. §후속 확인)

### 원인 (당시)
- **미확인.** 측정으로 고장 사인을 특정하지 못함.
- 운용 조건 (사실만, 인과 주장 아님):
  - `UQ_LIMIT` = 11V 로 설정돼 있었음.
  - 모터 3상 저항 20Ω → 정지 시 전류 계산값 = 11V / 20Ω ≈ 0.55A.
  - 부팅 시 정렬 루틴이 d축 전압을 캘리브레이션 구간(~3.6s) 동안 지속 인가.
  - 고장 확인용 정적 벡터 홀드(ud=6V)를 인가한 상태에서 위 증상 4가 진행됨.

---

## 후속 확인 : 드라이버 고장 아님, 배터리 전압 저하

**드라이버는 멀쩡했다.** 같은 SimpleFOC Mini 로 이후 밸런싱·텔레메트리 작업을 정상 진행했다
(2026-07-25 일지).

### 기록된 사실을 다시 읽으면

증상 4의 전압 **추이**가 드라이버 고장보다 공급 전압 저하에 맞는다.
(절대값 3.6/3.5/3.5V 자체는 근거로 쓰기 어렵다. 멀티미터는 PWM 평균을 읽고, 상-GND 전압은
0.5 중심 시프트와 역Clarke 분배가 섞인 값이라 명령한 `ud=6V` 와 직접 비교되지 않는다.)

- 3상이 **점진적으로** 감소해 0V 로 갔다. 소자가 죽으면 보통 즉시 0 이지, 서서히 내려가지 않는다.
- 증상 1의 "토크가 점점 약해짐"도 같은 곡선이다.
- 전원을 정리하고 다시 시험했을 때 같은 드라이버가 정상 동작했다.

### 왜 이 증상이 나오나

`foc.c` 는 duty 를 `u / V_SUPPLY + 0.5` 로 만드는데 `V_SUPPLY` 가 **11.3f 하드코딩**이다.
실제 배터리가 그보다 낮으면:

- 같은 uq 명령이 실제로는 더 낮은 전압으로 인가된다 → 토크가 명령보다 약함.
- 배터리가 계속 닳으면 이 괴리가 커진다 → 토크가 **점점** 약해짐.
- 펌웨어는 이 사실을 알 방법이 없다. 로그에는 정상 uq 가 찍힌다.

### 교훈

- **모터가 약해지면 배터리 전압부터 잰다.** 부품 고장을 의심하기 전에.
- 정지 상태 홀드는 역기전력이 없어 전류가 가장 크다. 배터리 소모도 이때 가장 빠르다.
- `V_SUPPLY` 하드코딩은 배터리 전압이 변하는 한 **튜닝 재현성을 깬다**. 어제의 K1·K2 가
  오늘 다르게 동작한다. 게인이 안 잡힐 때 후보로 기억해 둘 것.

---

## 다음 작업

### 안전 조치
1. ~~`UQ_LIMIT` ≤ 4V로 복귀~~ — 취소. 고장 원인이 과전류가 아니었으므로 11V 유지.
2. **정렬 후 캘리브레이션 중 모터 끄기** — 적용 완료. 정렬 d축 전압을 캘리브레이션(~2.6s)
   내내 홀드하던 것을 `foc_enable(false)` 로 끊었다. 배터리 소모·발열 모두 줄어든다.

### 튜닝 재개
3. **튜닝 전 배터리 전압 확인.** 전압이 다르면 같은 게인이 다른 토크를 낸다.
4. 게인 튜닝: 우선 **DEADBAND 0**으로 순수 K1·angle+K2·rate 안정성 확인 → K2(감쇠) 위주
   튜닝 → setpoint 정밀도.
5. 여전히 발산이면: 적분항 / 휠속도항(K3) 검토, 상보필터 계수·지연 점검.

### 상태
- 코드는 **fcf9d27** 에 밸런싱 동작 상태로 커밋됨.
- 어려운 부분(I2C 버스 멈춤, FOC 커뮤테이션, 밸런싱 제어 아키텍처)은 전부 해결·보존됨.

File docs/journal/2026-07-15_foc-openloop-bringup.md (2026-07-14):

# 작업 일지 - 2026-07-15 : FOC 오픈루프 브링업 (ESP-IDF 맨땅 구현)

BLDC 모터를 ESP-IDF에서 **맨땅 FOC(라이브러리 없이)**로 구동. 오픈루프 회전까지 검증한 기록.
시행착오를 순서대로 정리 — 각 문제의 원인과 해결, 그리고 배운 점(면접 대비).

---

## 0. 목표와 방향 결정

- 목표: SimpleFOC Mini + 2804 BLDC를 ESP-IDF C로 직접 제어. Step 1 = 오픈루프 회전 검증.
- **맨땅 구현 결정 이유**: 임베디드 SW 포트폴리오. 라이브러리(esp_simplefoc)로도 IDF에서 가능하지만,
  PWM 페리페럴/제어 루프를 직접 다루는 경험이 기술력 어필에 유리.
- **중요한 전제**: SimpleFOC Mini = DRV8313 기반 **3-PWM 드라이버, 전류 센서 없음**.
  → 전류 루프가 없는 **전압 모드 FOC**만 구현. FOC의 제일 어려운 부분(전류 측정→PI 전류제어)이 빠짐.
  → 이 하드웨어 특성 덕에 맨땅 구현이 감당 가능한 난이도가 됨.

## 1. 컴포넌트 구조

`components/foc/` 신규 (flat 레이아웃):
- `foc.h` / `foc.c` : 전압모드 FOC 드라이버
- `CMakeLists.txt` : `REQUIRES esp_driver_ledc esp_driver_gpio`

핵심 API:
- `foc_set_phase_voltage(ud, uq, angle_el)` — 전압 벡터 → 3상 duty (FOC 핵심, 클로즈드루프도 재사용)
- `foc_openloop_velocity(vel, dt)` — 인코더 없이 전기각 강제 적분 (검증용)
- `foc_init` / `foc_enable`

알고리즘 파이프라인:
```
(ud, uq) + 전기각 → 역 Park → (α,β) → 역 Clarke → 3상 전압 → duty(=u/V_SUPPLY + 0.5) → LEDC
```

## 2. LEDC vs MCPWM 선택

- 3-PWM 드라이버라 데드타임/상보출력이 드라이버 칩 내부 처리 → MCPWM 강점 불필요.
- LEDC(단순)로 충분. 상세: [2026-07-15_ledc-vs-mcpwm.md](./2026-07-15_ledc-vs-mcpwm.md)

---

## 시행착오 기록 (순서대로)

### 문제 1. PWM 주파수 vs 해상도 충돌
- 시도: 20kHz(가청 위) + 12비트 해상도.
- 증상/원인: LEDC 최대 주파수 = `클럭(80MHz) / 2^해상도`. 12비트면 `80M/4096 ≈ 19,531Hz`가 한계.
  20,000Hz 요청은 이 한계를 초과 → `ledc_timer_config` 실패 위험.
- 이유: 클럭 고정 상태에서 해상도를 높이면 한 주기가 길어져 주파수 상한이 내려감(트레이드오프).
- 해결: **11비트로 낮춤**(2048단계, 최대 39kHz) → 22kHz 사용 가능.
  `PWM_FREQ_HZ=22000, PWM_RES=LEDC_TIMER_11_BIT, DUTY_MAX=2047`.
- 교훈: PWM 페리페럴에서 주파수와 해상도는 독립이 아니다. 고정 클럭에서 둘은 반비례.

### 문제 2. 코드 리뷰에서 발견한 버그 3개
직접 작성 후 점검 과정에서:
1. `foc_init`: `ESP_ERROR_CHECK(&cfg)` — `gpio_config()` **호출 자체가 누락**. 구조체 포인터를
   esp_err_t로 넘겨 부팅 즉시 abort 날 상태였음. → `ESP_ERROR_CHECK(gpio_config(&cfg))`.
2. `foc_init`: `ledc_channel_config_t`에서 `.duty` **중복 지정**(엉뚱한 값 후 0). 정리.
3. `foc_enable`: `for(i<2)` — 3상 중 **2개만** duty 0 처리. → `i<3`.
- 교훈: ESP-IDF는 `xxx_config_t` 채우기 → `xxx_config()` **호출**이 한 세트. 구조체만 채우고 호출을 빼먹기 쉬움.

### 문제 3. 모터가 회전 안 하고 떨기만 함 (제일 중요)
- 증상: 전원 인가 시 회전 없이 제자리 진동(cogging).
- 원인 분석(숫자로): FreeRTOS **기본 tick = 100Hz** → `vTaskDelay(1)` = **10ms** → 루프 100Hz.
  - 목표 10 rad/s(축) × pole_pairs 7 = 70 rad/s(전기) ≈ 11.1 전기회전/초.
  - 한 스텝(10ms)당 전기각 증가 = 70 × 0.01 = **0.7 rad ≈ 40°**.
  - 전기 1회전을 **9스텝**으로만 쪼갬 → 자기장이 40°씩 뚝뚝 점프 → 회전자가 못 따라가 진동.
  - 부드러운 회전엔 전기 1회전당 20~50스텝 필요 → 루프 1kHz 이상 요구.
- 해결: `CONFIG_FREERTOS_HZ = 1000` (menuconfig) → `vTaskDelay(1)` = 1ms = 1kHz 루프.
  (esp_simplefoc 공식 문서도 tick 1000Hz 필수라고 명시)
- 교훈: 실시간 제어 루프에서 **업데이트 주파수 vs 전기 주파수**의 비가 부족하면 이산화(discretization)로
  코깅/진동 발생. 제어 대상의 주파수를 알고 샘플링/갱신율을 그에 맞춰야 함.

### 문제 4. tick 올린 뒤에도 초기 진동
- 증상: 회전은 시작하나 초반에 떨림.
- 원인: 오픈루프는 회전자 위치를 모른 채 자기장을 강제 회전. 정지 상태에서 갑자기 고속(11 전기회전/초)을
  명령하면 회전자가 이미 빠른 자기장을 **처음부터 붙잡지 못하고 미끄러짐(slip)**.
- 해결: **속도 램프업** 추가. `vel`을 0에서 `accel=5 rad/s²`로 증가시켜 2초에 걸쳐 목표 도달.
  자기장이 서서히 빨라져 회전자가 처음부터 락(lock) 유지.
- 교훈: 오픈루프 기동은 저속 시작 또는 램프가 필수. 피드백이 없으니 급격한 명령을 못 따라간다.

### 문제 5. 램프 후에도 잔여 떨림 (오픈루프의 태생적 한계)
- 증상: 회전은 하나 미세 진동 잔존.
- 원인(근본): 오픈루프 전압모드의 구조적 한계.
  - 위치 피드백 없음 → 전압 벡터가 회전자와 최적 정렬 안 됨 → 토크 리플.
  - 코깅 토크(모터 자체 자기 걸림) 보정 불가. 저속·저전압일수록 두드러짐.
  - 고정 전압(2V) 인가 → 속도 무관하게 같은 전압 → 저속 구간 덜컹.
- 완화(제거는 불가): 구동 전압 소폭 ↑(코깅 극복, 발열 증가 감수), 극저속 구간 회피.
- 근본 해결: **클로즈드루프 FOC** — 다음 단계.

---

## 최종 상태 (Step 1 결과)

- ✅ 배선/드라이버/PWM 경로 전부 검증 (모터 회전 확인).
- ✅ 전압모드 FOC 파이프라인(역Park→역Clarke→SinPWM→LEDC) 동작.
- ⚠️ 잔여 진동은 오픈루프 태생적 한계 → 클로즈드루프에서 해결 예정.
- Step 1의 목적(경로 검증)은 달성. 오픈루프 미세 튜닝엔 시간 투자 안 함(어차피 클로즈드루프가 답).

## 다음 작업 (TODO)

1. **Step 2 — MT6701 인코더** (`components/encoder/`): I2C 0x06 메인버스 직결, 14bit, reg 0x03/0x04. 각도 읽기.
2. **Step 3 — 정렬/영점**: 전기각 고정 인가로 회전자 정렬 → pole_pairs 실측 확정(현재 7 임시), 전기각 offset 측정.
3. **Step 4 — 클로즈드루프 FOC**: 인코더 각도 → 전기각 → `foc_set_phase_voltage(0, uq, 전기각+90°)`.
4. 이후 3-IMU voting/융합 → 기울기 추정 → PID 밸런싱.

## 면접용 핵심 포인트 (요약)

- **전압모드 vs 전류모드 FOC**: 전류 센서 유무로 갈림. 우리 드라이버는 센서 없어 전압모드 → 전류 루프 생략.
- **PWM 주파수/해상도 트레이드오프**: 고정 클럭에서 `f_max = clk / 2^res`. 실제로 겪고 11비트로 조정.
- **LEDC vs MCPWM 판단**: 3-PWM 드라이버라 데드타임 불필요 → 단순한 LEDC 선택(근거 있는 결정).
- **제어 루프 주파수의 중요성**: 100Hz→1kHz 변경으로 코깅 해결. 이산화/샘플링율을 숫자로 분석.
- **오픈루프 vs 클로즈드루프**: 오픈루프의 한계(위치 피드백 없음→토크 리플/코깅)를 이해하고 단계적으로 접근.
- **디버깅 방법론**: 증상→숫자로 원인 계산→해결. 추측이 아니라 정량 분석으로 원인 특정.

## 코드 상태

- `components/foc/foc.c` : 전압모드 FOC 드라이버 (완성, 빌드 OK).
- `main/main.c` : Step 1 오픈루프 테스트(속도 램프 포함). MPU 센싱 로직은 `components/mpu6050`에 보존.

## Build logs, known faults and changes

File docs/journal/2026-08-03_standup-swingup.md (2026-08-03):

# 2026-08-03 : 누운 자세에서 일어서기 — 스윙업은 성공, 그러나 포기

> **상태: 중단. 코드는 전부 되돌렸다.**
> 스윙업이 목표 각도에 도달하는 것까지 확인했으나, 기능 자체를 접기로 했다.

로봇은 이미 혼자 균형을 잡는다(2026-07-28 일지). 다음으로 원한 건 **눕혀 놓아도 스스로
일어나는 것**이었다. 대시보드 버튼 하나로 시작해서 균형 자세까지 올라오는 그림이다.

넘어야 할 각도는 이렇다. 눕힌 자세가 **60도**, 밸런싱 제어가 손을 놓는 한계(`TILT_CUTOFF`)가
**35도**다. 즉 **약 30도를 들어 올려야** 밸런서가 받아 준다.

---

## 1. 먼저 계측 도구부터 만들었다

누운 자세는 `TILT_CUTOFF` 밖이라 밸런싱 제어가 토크를 0 으로 낸다. 그래서 제어를 우회해
정해진 시간만 모터를 돌리는 **계측용 기동**을 대시보드에 넣었다. 전압, 시간, 제동 시간을
넣고 버튼을 누르면 펌웨어가 알아서 멈추고 결과를 로그로 찍는다.

두 가지 방식을 쟀다.

- **그냥 밀기:** 드는 방향으로 정해진 시간 동안 토크를 건다.
- **제동 기동:** 휠을 반대로 감아 두었다가 급제동한다. 감속의 반작용으로 몸을 던져 올린다.

---

## 2. 실측

| 조건 | 휠 최고 [rad/s] | 들림 |
|---|---|---|
| 125Hz, 6V, 그냥 밀기 1000ms | 52 | **7.2도** |
| 125Hz, 6V, 스핀 1500 + 제동 450 | 48 | 4.2도 |
| 125Hz, **10V**, 스핀 1500 + 제동 450 | 51 | 3.6도 |
| **200Hz**, 6V, 스핀 3000 + 제동 500 | **63** | **7.7도** |

### 루프 주기가 휠 속도를 막고 있었다

모터의 극쌍이 7 이라 축이 한 바퀴 도는 동안 자기장은 7바퀴를 돌아야 한다. 제어 루프가
125Hz 면 자기장 갱신이 초당 125번뿐이라, 휠이 빨라지면 **자기장이 회전자를 못 따라간다.**
계산상 상한이 약 55 rad/s 였고 실측이 정확히 50 에서 막혔다.

**200Hz 로 올리자 휠이 63 까지 올라가고 들림도 두 배가 됐다.** 병목이 맞았다.

### 전압은 병목이 아니었다

6V → 10V 로 67% 올렸는데 휠은 50 → 51, 들림은 오히려 줄었다. 이유는 파형이 잘리기
때문이다. 공급 전압의 절반(약 5.8V)을 넘으면 사인파 꼭대기가 잘려 나가고, 실제로 모터에
걸리는 기본 성분은 7.4V 근처에서 더 안 오른다. 그 위로는 이득 없이 발열만 는다.

### 진짜 병목은 드라이버 전류였다

근거 두 가지다. 스핀업 초기 가속도(약 60 rad/s²)와 제동 감속도(약 56)가 거의 같고,
**전압을 67% 올려도 감속도가 안 변한다.** 전압이 아니라 전류가 잘리고 있다는 뜻이다.
쓰는 드라이버(SimpleFOC Mini, DRV8313)는 연속 2.5A 급이다.

### 들림은 토크가 정한다. 시간도 운동량도 아니다

제동 시간을 200ms 에서 475ms 로 늘려 소모 운동량을 2.5배로 키웠는데 **들림은 평평했다.**

이유는 몸이 정지하는 지점이 정해져 있기 때문이다. 휠이 몸에 주는 반작용 토크와 중력이
몸을 끌어내리는 토크가 같아지는 각도에서 멈춘다. 이걸 **정적 평형점**이라 부른다. 토크가
같으면 아무리 오래 밀어도, 아무리 많은 운동량을 써도 그 각도를 못 넘는다.

**7.7도가 그 평형점이었다.**

---

## 3. 배제된 방법들

| 방법 | 왜 안 되나 |
|---|---|
| 직접 밀어 올리기 | 최대 전압에서도 7~8도. 30도는 불가능 |
| 전압 올리기 | 과변조로 포화. 위 참조 |
| 휠을 무겁게 | 한때 유력했으나 **틀렸다.** 무거운 휠은 토크를 안 키우고 지속 시간만 늘리는데, 지속 시간은 효과가 없다는 게 확인됐다 |
| 커뮤테이션이 붕괴해 제동이 약하다는 가설 | 제동 감속도가 시간에 대해 완벽히 선형이라 아니다 |

---

## 4. 스윙업 — 평형점에 묶이지 않는 유일한 방법

한 번 밀기가 정적 평형점에 걸린다면, **여러 번 나눠 밀면 된다.**

그네를 생각하면 쉽다. 한 번 밀어서 높이 올릴 수 없어도, 흔들리는 박자에 맞춰 계속 밀면
진폭이 점점 커진다. 도달 높이를 정하는 게 순간의 힘이 아니라 **쌓인 에너지**이기 때문이다.
정적 평형점은 순간의 토크가 정하는 한계라, 에너지를 쌓는 방식은 여기 안 묶인다.

덤도 있다. 한 방향으로만 밀면 휠이 최고속에 닿아 토크가 사라지는데, 스윙은 반주기마다
방향이 뒤집혀 **휠이 한쪽으로 계속 감기지 않는다.**

### 제어 법칙

몸이 도는 방향으로 토크를 걸면 에너지가 들어간다.

```
uq = +K · sign(몸의 각속도)
```

**부호는 유도하지 않고 코드에 이미 박힌 실측값에서 끌어냈다.** 계측용 기동이 쓰는
"몸을 드는 방향" 이 실기에서 확인된 값이라, 거기서 위 관계를 얻었다. 이 프로젝트는
부호를 계산으로 유도해 두 번 틀린 적이 있어(2026-07-28 일지) 유도를 믿지 않기로 했다.
대신 화면에서 부호를 뒤집을 수 있게 만들어 두었다.

세부 처리가 셋 필요했다.

- **시동** — 멈춰 있으면 각속도가 0 이라 위 법칙이 아무 일도 안 한다. 첫 구간만 정해진
  방향으로 밀어 흔들림을 만든다.
- **떨림 방지** — 각속도가 0 근처에서 부호가 파닥이면 토크도 같이 파닥인다. 좁은 구간을
  두고 그 안에서는 직전 부호를 유지한다.
- **휠 폭주 방지** — 반주기가 비대칭이면 휠 속도가 한쪽으로 밀린다. 상한을 넘는 방향으로는
  토크를 끊는다. 이때 "명령 부호와 휠이 도는 부호의 관계" 를 추정하지 않고 **시동이 끝나는
  시점에 한 번 실측해서** 썼다. 추정했다가 틀리면 반대쪽을 막아 버린다.

### 잡아챌 때의 함정

피크가 35도 안에 들어오면 밸런싱 제어로 넘긴다. 그런데 그 순간 **휠이 빠르게 돌고 있다.**
밸런싱 제어에는 휠 속도 항이 있어서(`BAL_K3` = +0.3 V/(rad/s)), 휠이 30 rad/s 면 그것만으로
9V 가 나와 전압 상한을 포화시킨다. 잡아채자마자 반대로 던져 버릴 수 있다.

그래서 넘긴 직후 0.5초 동안 휠 속도 항을 0 부터 서서히 넣도록 했다. 이 항은 원래 "기준
자세가 틀어졌다" 를 아주 느리게 잡는 용도라 잠깐 빠져도 균형에 지장이 없다.

---

## 5. 결과 — 첫 시도에 성공했다

6V, 상한 8초, 잡아챌 각도 30도. 부호는 기본값 그대로였다.

```
스윙 6.0V 기본: 잡아챔 — 60.8도 → 33.1도, 6회 2.21초 (반주기 368ms),
휠 -10 rad/s, 피크 [54.8 77.1 37.9 74.9 33.1 72.0]
```

| 회차 | 드는 쪽 | 넘어가는 쪽 | 진폭 | 흔들림의 중심 |
|---|---|---|---|---|
| 1 | 54.8 | 77.1 | 22.3 | 66.0 |
| 2 | 37.9 | 74.9 | 37.0 | 56.4 |
| 3 | 33.1 | 72.0 | 38.9 | 52.6 |

두 가지가 동시에 일어났다. **진폭이 22도에서 39도로 자랐고, 흔들림의 중심이 66도에서
52.6도로 올라왔다.** 에너지가 쌓이면서 몸 전체가 세워지는 쪽으로 옮겨간 것이다.

**2.21초, 6회 만에 잡아챌 각도에 닿았다.** 한 번 밀기가 7.7도에서 막히던 것과 비교하면
다른 차원이다.

덤으로 알아낸 것도 있다. **60도 정지 자세는 바닥에 걸린 한쪽 벽이 아니라 자유로운
평형점이었다.** 33도에서 77도까지 양쪽으로 넘나든다. 이걸 몰랐다면 한쪽으로만 미는
설계를 했을 것이다.

잡아채는 순간도 걱정보다 나았다. 직전 반환점이 33.1도였고 다음 회차는 28도쯤이 될
참이었으니, 30도에서 잡은 건 **반환점 직전 — 몸이 가장 느린 지점**이었다. 휠도 -10 rad/s
로 느려서 위에서 만든 페이드가 딱히 필요하지도 않았다.

---

## 6. 그런데 포기했다

잡아챈 뒤 실제로 서 있었는지는 **확인하지 않았다.** 그 답을 듣기 전에 일어서기 기능
자체를 접기로 결정했다.

**관련 코드를 전부 되돌렸다.** 스윙업도, 계측용 기동도, 그에 딸린 서버·대시보드 코드도
저장소에 없다.

### 롤백으로 같이 사라진 값들

일어서기와 무관한 튜닝값인데 한 덩어리라 함께 되돌아갔다. 나중에 밸런싱을 다시 손댈 때
필요할 수 있어 남긴다.

| | 현재 코드 | 되돌리기 전 | 근거 |
|---|---|---|---|
| `LOOP_PERIOD_MS` | 8 (125Hz) | **5 (200Hz)** | 커뮤테이션 상한. 휠 50 → 63 rad/s |
| `VEL_LPF` | 0.2 | 0.125 | 위 주기에 물린 값 (시정수 40ms) |
| `COMP_ALPHA` | 0.98 | 0.9874 | 위 주기에 물린 값 (시정수 0.39초) |
| `UQ_LIMIT` | 6.0 | 7.5 | 그 위는 이득 없이 발열만 |
| `V_SUPPLY` | 11.6 | **11.1** | **전압계 실측값. 11.6 이 틀린 값이다** |

`COMP_ALPHA` 와 `VEL_LPF` 는 루프 주기에 물려 있다. 주기를 바꾸면 필터 세기를 유지하려면
같이 바꿔야 한다.

**`V_SUPPLY` 만 성격이 다르다.** 나머지는 취향이나 튜닝이지만 이건 실제로 재서 확인한
값이라, 지금 코드에 들어 있는 11.6 은 그냥 틀렸다. 밸런싱을 다시 만질 일이 있으면 이것부터
고쳐야 한다.

---

## 참고 — 남은 후보 (전부 보류)

일어서기를 다시 꺼낼 일이 있다면 여기서 시작하면 된다.

1. **루프를 더 올린다** (250~300Hz). 200Hz 하나로 두 배가 됐으니 여지가 있다. 다만 자유
   주행이 247Hz 라 여유가 빠듯하다
2. **SVPWM** — 파형 왜곡 없이 약 15% 더 뽑는 변조 방식. 과변조 발열을 줄이는 의미가 더 크다
3. **하드웨어** — 드라이버 전류 용량이 병목의 정체다. 무게중심 낮추기도 후보

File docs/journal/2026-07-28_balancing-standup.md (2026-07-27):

# 2026-07-28 : 밸런싱 — 혼자 서다

> **상태: 성공.** 손을 놓아도 스스로 균형을 유지한다.

최종 게인:

| | 값 | 역할 |
|---|---|---|
| `BAL_K1` | **−4.0** V/도 | 기울어진 만큼 되민다 |
| `BAL_K2` | **−1.0** V/(도/s) | 넘어지는 속도를 보고 미리 막는다 |
| `BAL_K3` | **+0.3** V/(rad/s) | 휠이 한쪽으로 감기면 목표 자세를 옮긴다 |
| `DEADBAND` | **0.0** 도 | 껐다 (§1) |
| `UQ_LIMIT` | 6.0 V | |

---

## 진행 방식

부호가 반대면 기울수록 넘어지는 쪽으로 세게 밀어붙인다. 로그를 보고 알아차릴 시간이 없다.
그래서 모터를 물리기 전에 단계를 나눴다.

| 단계 | 내용 | 확인한 것 |
|---|---|---|
| 3-A | `DRIVE_MOTOR 0` — 드라이버 EN 을 끄고 `uq` 를 계산해 찍기만 | 각도·각속도 부호가 서로 맞는가 |
| 3-B | `UQ_LIMIT 3V` 로 낮추고 손으로 잡은 채 구동 | 휠이 도는 방향이 복원 방향인가 |
| 3-C | 게인 튜닝 | |

**3-A 에서 제어 루프를 따로 만들지 않은 것이 핵심이다.** `foc_apply_torque()` 까지 그대로
호출하고 드라이버 EN 만 껐다. 계측용 루프를 따로 짰다면 실제로 돌릴 코드와 다른 코드를
검증하게 된다. 노이즈 조사([2026-07-27](2026-07-27_foc-noise-isolated.md))에서 진단 모드가
여러 개 얹혀 결론이 안 나던 것과 같은 함정이다.

3-A 판정: 왼쪽으로 기울일 때 각도 +, 각속도 + 로 **부호가 일치**했다.
자이로 축이 틀렸다면 상보필터 안에서 자이로 적분과 가속도 각도가 서로 반대로 당겨
각도가 밀리거나 튄다. 그런 증상이 없었으므로 축(`gx`, `ay`/`az`)이 맞다.

---

## 1. 데드밴드가 첫 1초를 죽이고 있었다 ★

첫 폐루프는 0.7초 버티고 넘어졌다. 10Hz 로그를 찍자 원인이 한 줄에 드러났다.

```
10.9초  각도 0.9도  각속도 4.3도/s  uq -1.74V
11.0초  각도 1.4도  각속도 0.4도/s  uq -3.04V   ← 각속도는 1/10 인데 uq 는 2배
```

계산이 정확히 맞는다.

| 시점 | 각도 | 계산 | 로그 |
|---|---|---|---|
| 10.9초 | 0.9도 (데드밴드 안) | `0 + (-0.4×4.3)` = −1.72 | −1.74 |
| 11.0초 | 1.4도 (밖) | `(-2.0×1.4) + (-0.4×0.4)` = −2.96 | −3.04 |

`|각도| < 1.0` 인 동안 **각도항이 완전히 꺼져 있었다.** 작동한 건 감쇠뿐이다.

**감쇠만으로는 못 세운다.** 넘어지는 속도를 늦출 뿐 되돌리지 못한다. 도립진자는 위치
되먹임이 있어야 복원된다. 그 1초 동안 휠은 이미 −9.5 rad/s 까지 감겨 예산을 축내고 있었다.

`DEADBAND` 를 0 으로 바꾼 결과:

| | 1.0도 | 0 |
|---|---|---|
| 각도 0.1 → 1.0도 걸린 시간 | 0.65초 | **1.45초** |
| 각도 0.9도일 때 휠 속도 | −9.5 | **−22.7** |

저항 시간이 2.2배가 됐다. 우려하던 떨림은 거의 없었다(정지 구간에서 `uq` ±0.3V).

데드밴드는 미세 진동을 막으려고 넣은 것이었는데, **복원력이 0 인 구간을 만드는 대가**가
훨씬 컸다. 주석에도 재검토 대상으로 적혀 있던 항목이다.

---

## 2. 게인 크기 — 전력을 언제 쓰느냐의 문제

데드밴드를 껐는데도 양상은 같았다. 각속도가 한 번도 음수로 내려가지 않았다.

```
11.7초  1.5도/s   ← 초기 기울기
11.8초  0.3도/s   ← 늦추는 데는 성공
12.5초  1.5도/s   ← 다시 벌어짐
13.3초  6.5도/s   uq -5.24V  ← 아직 포화 아닌데 지고 있다
13.4초  10.6도/s  uq -6.00V
```

**늦추기만 하고 되돌리지 못했다.** 그리고 포화되기 전에 이미 졌다 — 13.3초에 0.76V 여유가
있는데도 각속도가 커진다.

전압을 언제 쓰는지가 문제였다.

| 시점 | 각도 | 쓰는 전압 | 여유 |
|---|---|---|---|
| 11.7초 | 0.1도 | 0.70V | 88% 남음 |
| 13.4초 | 1.8도 | 6.00V | 0% |

**초반 1.3초 동안 힘의 10~25% 만 쓰고 있었다.** 전력을 다 쏟는 시점이 1.8도인데 그때는
각속도가 10도/s 라 관성 때문에 못 세운다.

도립진자는 작을 때 잡아야 한다. 기울기가 커지면 중력 토크도 커지고 이미 붙은 속도도
되돌려야 해서, 전압을 다 써도 늦다.

**사용자 관측이 방향을 정했다** — "초기에 거의 반대쪽으로 넘어갈 정도로 순간 토크를 크게
주고 다시 보정하는 게 필요해 보인다". 이건 별도 알고리즘이 아니라 게인 크기 문제다.

`K1` 을 올려 6V 도달 기울기를 3.0도 → 1.0도로 당겼다.

---

## 3. K2 는 잡음 증폭기다 ★

`K1`·`K2` 를 같이 3배로 올리자 **모터에서 갈리는 소리**가 났다. 버티는 시간은 늘었다.

처음엔 과변조를 의심했다. `foc.c` 가 전압을 duty 로 바꿀 때 선형 한계가 `V_SUPPLY / 2` 라,
`uq` 6.0V 가 그 한계(당시 설정 11.3V 기준 5.65V)를 넘어 사인파 꼭대기가 잘리고 있었다.

**틀렸다.** 배터리를 재니 11.6V 였고, 그러면 한계가 5.8V 라 3.4% 만 넘는다. 그 정도로
그런 소리는 안 난다. (다만 `V_SUPPLY` 가 11.3 으로 낡아 있던 건 사실이라 11.6 으로 고쳤다.
명령보다 2.7% 높은 전압이 나가고 있었다.)

진짜 원인은 **채터링**이었다.

`rate` 는 자이로 raw 값이라 항상 잡음이 섞여 있다. `K2 = 0.4` 일 때 ±0.2V 수준이던 것이
`K2 = 3.0` 에서는 **±1.5V 짜리 명령**이 된다. `uq` 가 기울기와 무관하게 초당 수십 번
뒤집히고, 전압 벡터가 180도씩 반전되며 코일 전류가 계속 방향을 바꾼다. 그게 소리였다.

**떨림 크기는 `K2` 값만으로 정해진다. `K1` 과 무관하다.** 잡음이 들어오는 창구가
각속도항 하나뿐이기 때문이다. 각도 신호는 자이로를 적분한 값이라 훨씬 조용하다.

그래서 `K1` 은 높게 두고 `K2` 만 −3.0 → −2.0 → **−1.0** 으로 내렸다. 소리가 사라졌고
2초를 버텼다.

> 감쇠가 모자라면 `K2` 를 올리는 게 아니라 **각속도 신호를 걸러야 한다.**
> 자이로 잡음은 넓은 주파수에 퍼져 있고 실제 기울기 변화는 훨씬 느리므로,
> 20~30Hz 저역통과로 잡음만 깎고 감쇠는 유지할 수 있다. 이번엔 필요 없었다.

---

## 4. K3 — 부호가 반대였다 ★

2초를 버티지만 **한쪽으로 조금씩 밀리다 넘어졌다.** 휠 속도가 처음부터 끝까지 한 방향으로만
증가하고 한 번도 되감기지 않았다.

똑바로 선 자세를 `각도 0` 으로 잡았지만 **진짜 균형점이 거기가 아니다.** 조립 오차·무게중심
때문에 0.1~0.3도쯤 어긋나 있다. 제어기는 각도를 0 으로 유지하려 하고, 그 자세는 실제로는
살짝 기운 상태다. 기운 자세를 유지하려면 휠을 계속 더 빠르게 돌려야 하는데 휠 속도에는
한계(약 55 rad/s)가 있다. 닿는 순간 토크가 사라진다.

**버티는 시간만 늘어날 뿐 결말은 정해져 있었다.**

기준 각도를 손으로 더 정확히 잡는 건 답이 아니다. 눈으로 0.1도를 맞출 수 없고 조립을
건드릴 때마다 다시 해야 한다.

해법은 휠 속도를 되먹이는 것이다. **휠이 한쪽으로 계속 감긴다는 것 자체가 "기준이 틀렸다"는
신호**이므로, 그 신호로 목표 자세를 옮기면 제어기가 스스로 진짜 균형점을 찾아간다.

```c
uq = K1*angle + K2*rate + K3*wheel_vel;
```

### 두 가지가 예측과 달랐다

**부호.** 나는 "음수 휠 속도를 감속시키려면 양수 토크가 필요하므로 K3 는 음수" 로 유도해
`-0.05` 를 제안했다. **실기에서는 양수가 맞았다.** 유도가 틀렸다.

**크기.** `0.05` 를 제안했는데 실제로 동작한 값은 **`0.3`, 6배**다.

부호를 계산으로 정할 때는 휠 토크 방향과 몸체 반동 방향, 엔코더 증가 방향, 정렬 오프셋이
모두 얽힌다. 이 프로젝트에서 부호를 계산으로 맞춘 적이 한 번도 없다
(`BAL_K1` 도 "실기 확인해 반대라 음수" 로 적혀 있다). **부호는 재는 것이지 유도하는 게 아니다.**

`K1` 은 −6.0 에서 **−4.0** 으로 내렸다. K3 가 붙으면서 과했다.

---

## 배운 것

1. **복원력이 0 인 구간을 만들지 말 것.** 데드밴드가 첫 1초를 통째로 죽였다
2. **전력을 언제 쓰는가가 얼마나 쓰는가보다 중요하다.** 다 쓸 때쯤이면 늦다
3. **잡음이 들어오는 창구를 특정할 것.** 떨림은 `K2` 하나로 정해졌다. `K1` 을 같이 내렸다면
   원인을 못 찾고 성능만 잃었을 것이다
4. **부호는 실기에서 잰다.** 계산으로 두 번 틀렸다(`BAL_K1`, `BAL_K3`)
5. **10Hz 로그가 결론을 만들었다.** 0.7초짜리 현상을 1초에 한 줄로는 볼 수 없다.
   창 길이를 바꿀 거면 `loop Hz` 처럼 창 길이에 의존하는 지표도 같이 고쳐야 한다

---

## 알려진 한계

- **`uq` 6.0V 는 선형 한계(`V_SUPPLY / 2` = 5.8V)를 3.4% 넘는다.** 사인파 꼭대기가 살짝
  잘린다. 더 필요하면 **SVPWM**(공간벡터 변조)으로 약 15% 더 뽑을 수 있다
- 휠 최고 속도 약 55 rad/s. 큰 외란을 받으면 여전히 포화될 수 있다
- 센서는 mux 채널 0 하나만 쓴다. 3개 voting 은 미구현

## 남은 일

1. 외란 내성 시험 — 밀었을 때 회복하는가
2. 4단계 텔레메트리. **`sdkconfig.defaults:8` 의 `CONFIG_ESP_WIFI_TASK_PINNED_TO_CORE_1` 이
   `unknown kconfig symbol` 로 무시되고 있다.** Wi-Fi 드라이버 태스크가 기본값인 코어 0
   (제어 코어)에 남아 있다. 붙이기 전에 처리할 것
3. 3센서 voting
4. 문서·주석의 "MPU6050" → MPU6500 정정

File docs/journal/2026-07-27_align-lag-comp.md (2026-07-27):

# 2026-07-27 : 정방향/역방향 속도 비대칭 — 양방향 정렬 + 지연 보상

> **상태: 해결.** 정방향/역방향 속도차 **31 → 5 rad/s**.
> [같은 날 노이즈 일지](2026-07-27_foc-noise-isolated.md) §곁가지 발견에서 미해결로 남긴 것.

노이즈를 잡고 나니 남은 문제가 드러났다. 루프가 느려질수록 역방향만 무너졌다.

| loop | 정방향 | 역방향 |
|---|---|---|
| 999Hz | +45 rad/s | −47 rad/s |
| 250Hz | +45 rad/s | **−14 rad/s** |

그리고 부팅마다 정렬 기계각이 217.8° / 311.9° / 326.9° 로 제각각이었다.

---

## 1. 양방향 정렬

### 바꾼 것

d축에 전압을 걸고 1초 기다리던 것을, **전기각을 0 → 2π → 0 으로 왕복 스윕**하고
양 끝에서 기계각을 재는 방식으로 바꿨다. 두 오프셋을 단위벡터로 평균낸다.

양 끝은 둘 다 전기각 0 지점이라(정방향 끝은 2π ≡ 0) `offset = -기계각 × 극쌍수` 가
양쪽에 똑같이 성립한다. 끝점 각도는 16샘플 단위벡터 평균으로 잡는다.

- `main.c` : `align_rotor()`, `read_angle_avg()`
- `foc.c` : `foc_align(angle_fwd, angle_rev)`

### 실측

```
FOC: 정렬 오프셋 -109.9도 (정방향/역방향 편차 -1.7도)
```

| | 이전 (단방향) | 지금 (왕복) |
|---|---|---|
| 정방향 250Hz | +45 | **+32** |
| 역방향 250Hz | **−14** | **−42** |
| 정방향/역방향 차 | 31 | **10** |
| 부팅 재현성 | 217.8 / 311.9 / 326.9° 제각각 | **−109.9° 근처 반복** |

전 구간 엔코더실패 0, MPU실패 0, 손상 0. 최대변화도 정 7.7° / 역 10.0° 로
비가 1.30 — 속도비 1.31 과 일치한다. 값이 틀린 게 아니라 진짜 속도차다.

### ★ 원인 정정 : 코깅이 아니라 정지마찰이었다

노이즈 일지에는 원인을 **코깅 편향**으로 적었다. 진행 방향에 따라 코깅이 회전자를
붙잡는 방향이 반대라, 한 방향에서만 재면 그 편향이 오프셋에 남는다는 설명이었다.

**측정된 정방향/역방향 편차가 −1.7° 뿐이다.** 코깅 몫은 그 절반인 0.85°(전기각)다.
0.85° 로 31 rad/s 의 비대칭이 나올 수는 없다. 처방은 맞았지만 이유가 틀렸다.

실제로 고쳐진 것:

```
예전 : 임의 위치에서 ud 인가 → 1초 대기
       회전자가 가장 가까운 안정점으로 끌려가지만 정지마찰 때문에 끝까지 안 간다.
       남은 오차 몇 도(기계각)가 ×7 되어 전기각 수십 도가 된다.
       시작 위치가 매번 달라 잔류 오차도 매번 다르다 → 부팅마다 값이 바뀐다.

지금 : 전기 1회전을 끌고 지나간다
       정지마찰이 깨지고 회전자가 자계를 실제로 추종한다.
```

부팅 재현성이 같이 해결된 것이 이 설명의 근거다. 코깅 편향이라면 회전자가 멈추는
자리에 따라 값이 계속 달라져야 하는데, 왕복 스윕을 넣자 −109.9° 로 고정됐다.

---

## 2. 커뮤테이션 지연 보상

### 왜 필요한가

엔코더를 읽고 전압 벡터를 내보낸 뒤 다음 갱신까지 회전자는 계속 돈다.
자계가 회전자보다 한 루프치 뒤에 선다.

```
지연[전기각] = 휠속도 × 극쌍수 × 루프주기
```

토크는 자계가 회전자보다 90° 앞설 때 최대다. 지연은 그만큼을 깎는다.

| loop | 속도 | 지연 | 유효 토크각 | sin |
|---|---|---|---|---|
| 999Hz | 46 rad/s | 18° | 72° | 0.95 |
| 250Hz | 37 rad/s | **59°** | **31°** | **0.52** |

### 바꾼 것

읽은 각도가 아니라 **다음 갱신 시점의 예상 위치**에 자계를 세운다.

```c
float adv = LAG_COMP * wheel_vel * dt;
foc_apply_torque(dir * TEST_UQ, angle + adv, offset);
```

`LAG_COMP 1.0` = 한 루프치. `wheel_vel` 이 튀어도 벡터가 날아가지 않도록
`ENC_MAX_VEL × dt` 로 상한을 둔다. `0.0` 이면 보상 없음이라 A/B 비교가 된다.

### 실측

정방향/역방향 차 **10 → 최대 5 rad/s**. 손상 0 유지, 타격음 없음.
(이 판에서는 절대 속도값을 기록하지 않았다. §4 에 있다.)

---

## 4. 로그 출력 태스크 분리

`ESP_LOGI` 는 UART 송신 버퍼가 빌 때까지 CPU 가 제자리에서 기다린다(폴링).
190자 @115200 = 16.5ms. 이 기다림이 **제어 루프와 같은 태스크 안**에 있어서
그동안 커뮤테이션이 멈췄다. 40 rad/s 면 전기각 175° 진행 = 토크 반전.

제어 루프를 우선순위 10 태스크로 떼어내고, `app_main`(우선순위 1)이 로그를 맡는다.
통계는 길이 1 큐에 `xQueueOverwrite` 로 넘긴다 — 제어 루프는 어떤 경우에도 대기하지 않는다.

**코어는 안 나눴다.** 우선순위가 높으면 로그 태스크가 UART 를 기다리는 중이어도
제어 태스크가 즉시 뺏어온다. 코어 분리가 필요해지는 것은 우선순위로 밀어낼 수 없는
Wi-Fi 인터럽트가 붙을 때다.

### 실측

| | 정방향 | 역방향 | 차 |
|---|---|---|---|
| 250Hz | **+43** | **−42** | **1** |

999Hz 기준선(45~47)을 거의 회복했다. 최대변화도 정방향 10.3° / 역방향 10.0° 로
비가 1.03, 속도비 43/42 = 1.02 와 일치한다. 로그 출력 순간의 토크 충격은 사라졌다.

### 곁가지 : 지연 보상이 정렬 오차를 실제로 흡수한다

이 판의 정렬값이 이전 판과 달랐다.

| 부팅 | 오프셋 | 정방향/역방향 편차 |
|---|---|---|
| 이전 | −109.9° | −1.7° |
| 이번 | **−97.1°** | **+6.3°** |

13° 나 차이 나는데도 속도는 대칭이었다. 지연 보상 전이라면 이 정도 오차가 3.2배
비대칭을 만들었다. **동작점이 `sin` 이 평평한 90° 근처로 옮겨져 정렬 오차에 둔감해진 것**이
숫자로 확인됐다. 정렬 재현성이 완벽하지 않아도 되는 이유다.

---

## 3. 999Hz 대칭은 정렬이 맞다는 근거가 아니었다

노이즈 일지는 999Hz 에서 +45/−47 로 대칭인 것을 정렬이 정상이라는 근거로 읽었다.
**틀렸다.**

지연만으로는 비대칭이 안 생긴다. 양방향을 똑같이 깎기 때문이다.
비대칭이 나오려면 남은 오프셋 오차 ε 가 있어야 하고, ε 는 한 방향엔 더해지고
반대 방향엔 빠진다.

```
정방향 유효 토크각 = 90° − 지연 + ε
역방향 유효 토크각 = 90° − 지연 − ε
```

999Hz 에서는 지연이 18° 라 동작점이 72°, `sin` 이 평평한 구간이다. ε 가 몇 도 있어도
속도차가 거의 안 난다. 250Hz 에서는 동작점이 31° 로 `sin` 이 가파른 구간에 들어가
같은 ε 가 크게 증폭된다.

**즉 999Hz 대칭은 ε=0 의 증거가 아니라 ε 가 묻힌 상태였다.**
어떤 조건에서 증상이 안 보이는 것과 원인이 없는 것은 다르다.

같은 이유로 지연 보상은 두 가지를 동시에 해결한다.
동작점을 90° 근처로 되돌리면 (a) 양방향 속도가 올라가고
(b) `sin` 이 평평해져 남은 ε 의 영향이 저절로 묻힌다.
ε 를 직접 0 으로 깎는 것보다 확실하다.

---

## 결과

| | 정방향 | 역방향 | 차 |
|---|---|---|---|
| 단방향 정렬 | +45 | −14 | 31 rad/s |
| 양방향 정렬 | +32 | −42 | 10 |
| \+ 지연 보상 | (미기록) | | 5 |
| \+ 로그 태스크 분리 | **+43** | **−42** | **1** |

커밋 `5a90dd1`(정렬·지연 보상), `9aac44c`(태스크 분리).

---

## 남은 일

1. 3단계(밸런싱 제어), 4단계(텔레메트리)
2. **Wi-Fi 코어 고정이 안 먹고 있다.** `sdkconfig.defaults:8` 의
   `CONFIG_ESP_WIFI_TASK_PINNED_TO_CORE_1=y` 가 빌드 경고 `unknown kconfig symbol` 로
   무시된다. Wi-Fi 드라이버 태스크가 기본값인 **코어 0**(제어 코어)에 남아 있다.
   바로 아래 `LWIP_TCPIP_TASK_AFFINITY_CPU1` 은 정상 적용됐다. 텔레메트리 붙일 때 처리
3. `dt최대` 를 로그 줄에 추가 — 루프 주기 흔들림을 직접 보려면 필요하다
4. 문서·주석의 "MPU6050" → MPU6500 정정 (`WHO_AM_I = 0x70`)

밸런싱은 저속(수 rad/s)에서 돌기 때문에 지연이 전기각 5° 수준이다.
지금 잡은 비대칭은 고속 전용 현상이라 3단계에서는 거의 안 나타난다.

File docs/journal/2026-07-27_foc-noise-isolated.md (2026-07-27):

# 2026-07-27 : FOC 커뮤테이션 소음 — 원인 규명 및 해결

> **상태: 해결.** 원인은 **PWM 스위칭 잡음이 I2C 통신을 깨뜨리는 것**이었다.
> PWM 22kHz → 5kHz 로 낮추자 타격음이 사라졌다.
> 다만 5kHz 는 가청 대역이라 새 소음이 생긴다. 타협점 탐색이 남았다(§남은 일).

전날([2026-07-26](2026-07-26_foc-noise-investigation.md)) 추적이 교착에 빠져,
누적된 진단 코드를 전부 걷어내고 **최소 구성부터 하나씩 얹어 올라가는 방식**으로 바꿨다.

---

## 결론 : 인과 사슬

```
PWM 스위칭 (22kHz, 3상)
  → I2C 거래가 10ms 안에 안 끝남 (시간 초과, 초당 2~8회)
    → 그 직후 엔코더 읽기가 쓰레기값 (45 / 90 / 180도 틀어짐)
      → 전압 벡터가 엉뚱한 방향으로 한 루프 튐
        → "탁" 하는 타격음
```

각 화살표가 전부 숫자로 확인됐다. 마지막에 맨 앞(PWM 주파수)을 건드리자 맨 뒤(소리)가
사라져 사슬 전체가 닫혔다.

---

## 왜 방식을 바꿨나

전날까지 `main.c` 하나에 진단 모드 3개, 계측 변수 10개, 이상값 거부·재시도·예측·탈출구가
전부 얹혀 있었다. 변수가 너무 많아 무엇을 바꿔도 결론이 안 났다.

무엇보다 **기존 실험 행렬이 두 변수를 동시에 바꾸고 있었다.** "루프에서 MPU 를 읽느냐"
하나만 달랐지만, 그게 (a) 루프 주기와 (b) 버스 트래픽을 같이 바꿨다. 이 둘을 가르지
못한 채로 여러 판을 소모했다.

그래서 `main.c` 를 비우고 **최소 폐루프**부터 다시 쌓았다.

---

## 단계별 재구축 ★ 핵심

`배수` = 그 초의 최대 각도 변화 ÷ (그 순간 `dt` × 휠속도).
물리적으로 가능한 값이면 1.0, 크게 넘으면 엔코더가 틀린 값을 준 것이다.

| 단계 | 구성 | loop | 배수 | 소리 |
|---|---|---|---|---|
| 1 | 엔코더 커뮤테이션 + 고정 uq 3V | 999Hz | 0.7~1.0 | **무음** |
| 2-A | 위 + `vTaskDelay` 1→4ms | 250Hz | 0.9~1.4 | **무음** |
| 2-B | 1단계 + 루프에서 MPU 읽기 | 241~250Hz | **4.8~177.6** | **소음** |

### 1단계 (31초)

```
loop 999Hz  휠  45.8 rad/s  실패 0  최대변화 5.1도 (dt 2.0ms 설명가능 5.3도 = 1.0배)
loop 999Hz  휠 -49.4 rad/s  실패 0  최대변화 5.6도 (dt 2.0ms 설명가능 5.7도 = 1.0배)
```

- 엔코더실패 0, 최대변화 3.3~5.8도, 전부 `dt × 휠속도` 로 설명됨
- 휠 정방향 +43.8~47.4, 역방향 −43.3~−49.5 **(대칭)**
- 5초마다 1.5~1.7배가 찍히는 건 방향 전환 초라 휠속도 평균이 낮게 잡히는 것이고
  값이 틀린 것이 아니다

### 2-A 가 조용한 것이 무엇을 죽였나 (31초)

**루프 주기(커뮤테이션 갱신 주기)는 원인이 아니다.**

250Hz·45 rad/s 면 한 루프 동안 회전자가 전기각 **73°** 를 나아간다(`45 × 극쌍 7 × 4ms`).
전기각 오차가 90° 를 넘으면 구동 토크가 제동 토크로 뒤집히므로 여기서 소리가 날 것으로
예상했으나 **완전히 조용했다.** 최대변화 3.1~13.3도, 배수 0.9~1.4.

전날 세운 "커뮤테이션 지연으로 토크가 반전되어 나는 소리"라는 설명은 **틀렸다.**

### 2-B 가 시끄러운 것이 무엇을 확정했나

2-A 와 **루프 주기가 같다**(250Hz vs 247Hz). 다른 것은 통신선에 mux 전환 + MPU
14바이트 읽기가 끼어드는 것 하나뿐이다.

```
2-A  loop 250Hz  최대변화   4.1도 (dt 5.0ms 설명가능 4.1도 =   1.0배)   무음
2-B  loop 250Hz  최대변화 174.7도 (dt 4.0ms 설명가능 6.6도 =  26.6배)   소음
2-B  loop 243Hz  최대변화 111.1도 (dt 4.0ms 설명가능 0.6도 = 177.6배)   소음
```

MPU실패 초당 0~5회. 회전이 눈에 보이게 끊긴다.

---

## 원인 추적 : 추정 / 측정 방법 / 결과

**한 판에 한 가지만 바꿨다.**

| # | 추정 | 측정 방법 | 결과 |
|---|---|---|---|
| 1 | 통신 속도가 빠를수록 신호가 깨진다 | `I2C_FREQ_HZ` 50k / 100k / 400k, MPU 실패율을 **루프당 %** 로 환산 | ✗ **1.00 / 1.09 / 0.87%**. 8배 범위에 평평 |
| 2 | 엔코더 손상과 MPU 실패는 별개다 | 초 단위로 `MPU실패 0` 인 초의 손상 개수 확인 | ✗ **`MPU실패 0` → `손상 0`, 19/19 예외 없음** |
| 3 | 손상은 단발이라 다시 읽으면 정상값이 온다 | 이상값이 오면 즉시 재읽기 후 비교 | ✗ **0/306**. 단 실험 설계가 틀렸다(§손상이 짝으로) |
| 4 | 실패한 루프의 값만 버리면 된다 | `SKIP_AFTER_FAIL` 1 → 3 | ✗ 소리가 역방향에만 남음. **계측까지 오염** |
| 5 | mux 채널 전환이 실패한다 | `mpu6050.c` 에서 실패 지점을 mux 쓰기 / 데이터 읽기로 분리 | ✗ **mux 0, 데이터 100%** (36줄 전부) |
| 6 | 센서가 주소에 응답하지 않는다 | 실패를 `ESP_FAIL`(무응답) / `ESP_ERR_TIMEOUT`(시간초과) 로 분리 | ✗ **무응답 0, 시간초과 100%** (50줄 전부) |
| 7 | 엔코더 주소 0x06 이 버스를 교란한다 | **모터를 끄고** MPU단독 / MPU+엔코더 / MPU단독 각 10초 | ✗ **10,002회 중 시간초과 0건** |
| 8 | 모터가 돌 때만 생긴다 | 7번 결과를 회전 중 측정치(약 2%)와 대조 | ○ 확정 → 9번으로 |
| 9 | 스위칭·전류·회전 중 무엇인가 | 조건을 하나씩만 켜고 각 10초, 4회 반복 | ○ **스위칭만으로 발생, 전류는 기여 0** |
| 10 | 스위칭 가장자리 개수에 비례한다 | 같은 조건에서 PWM 22k / 10k / 5kHz, 3회 반복 | ○ **0.97 / 0.35 / 0.04%** |

---

### #1 상세 : I2C 통신 속도

루프 주기가 같이 변하므로 "초당 몇 회" 로는 비교가 안 된다. 루프당 %로 환산했다.

| 속도 | loop | MPU실패/초 | **루프당** |
|---|---|---|---|
| 50kHz | 165Hz | 1.65 | 1.00% |
| 100kHz | 247Hz | 2.7 | 1.09% |
| 400kHz | 480Hz | 4.17 | **0.87%** |

8배 범위에 1.09 → 0.87%. 신호 품질 문제라면 8배 올렸을 때 급격히 나빠져야 한다.

### #2 상세 : MPU 실패와 엔코더 손상은 한 몸이다

100kHz 기준 40초 측정:

| 항목 | 값 |
|---|---|
| 손상 | 68회 / 약 9,600 루프 = **0.71%** |
| MPU실패 | **3.2%** |
| 손상 0 인 초 | 40% |

판정 기준이 정확함도 같이 확인됐다. **겹치는 구간이 없다:**

| | 최대변화 |
|---|---|
| 손상 0 인 초 | 14.7 ~ **31.0도** |
| 손상 있는 초 | **53.2** ~ 178.9도 |

이후 41초 구간에서 `MPU실패 0` 인 초 19개가 **전부** 손상 0 이었고, 손상이 난 초는
**전부** `MPU실패 > 0` 이었다. 예외 0건.

엔코더(MT6701)와 MPU 는 서로 다른 부품인데 같이 실패하고 같이 멀쩡하다.
**공통점은 같은 I2C 통신선뿐이다.**

손상 크기가 **45 / 90 / 180도 근처에만 몰린다.** 14비트 각도값의 상위 바이트에서
한 자리가 뒤집히면 정확히 2048 / 4096 / 8192 카운트 = 45 / 90 / 180도가 틀어진다.

### #9 상세 : 스위칭·전류·회전 가르기 (4회 반복)

읽기는 세 구간 모두 MPU + 엔코더로 동일. 모터 상태만 바꿨다.

| 구간 | 스위칭 | 전류 | 회전 | 시간초과율 (4회) | 평균 |
|---|---|---|---|---|---|
| A 정지 | ✗ | ✗ | ✗ | 0.00 / 0.00 / 0.00 / 0.00 | **0.00%** |
| B 스위칭만 | **O** | ✗ | ✗ | 0.67 / 0.82 / 0.92 / 0.67 | **0.77%** |
| C 전류까지 | O | **O** | ✗ | 0.73 / 0.86 / 0.92 / 0.61 | **0.78%** |
| D 회전 | O | O | **O** | (별도 측정) | **약 2%** |

B 는 세 상 듀티가 전부 0.5 로 같아 **코일 양단 전압차가 0 = 전류가 흐르지 않는다.**
그런데도 0.00% → 0.77% 로 뛴다.

```
스위칭   0.77%p   ← 전부 여기서 나온다
전류     0.01%p   ← 기여 없음
회전     1.2%p    ← 추가로 악화
```

B·C 에서 `무응답` 이 처음 나타났다(0~7건). 회전 중엔 0 이었다.
스위칭 잡음이 가끔 주소 구간까지 건드린다는 뜻이다.

### #10 상세 : PWM 주파수 (3회 반복)

같은 조건(듀티 0.5, 전류 없음, MPU + 엔코더 읽기)에서 주파수만 바꿨다.

| PWM | 시간초과율 (3회) | 평균 |
|---|---|---|
| 정지 | 0.00 / 0.00 / 0.00 | **0.00%** |
| 22kHz | 0.98 / 0.98 / 0.95 | **0.97%** |
| 10kHz | 0.43 / 0.49 / 0.12 | **0.35%** |
| 5kHz | 0.12 / 0.00 / 0.00 | **0.04%** |

5kHz 는 3회 중 2회가 3,334회 읽기에 **실패 0건**.

주파수를 4.4배 낮췄는데 실패는 24배 줄었다. **단순 비례보다 가파르다.**
가장자리 개수만의 문제가 아니라 스위칭 강도(di/dt)도 관여하는 것으로 보인다.

---

## 해결 확인 : PWM 5kHz 로 회전 (20초)

2-B 상태 그대로에서 **PWM 주파수만** 22kHz → 5kHz.

```
loop 248Hz  휠 -40.2 rad/s  엔코더실패 0  MPU실패 0(0.00%)  손상 0(0.00%)
            최대변화 27.7도 (dt 12.0ms 설명가능 27.6도 = 1.0배)
```

| 항목 | 22kHz | 5kHz |
|---|---|---|
| MPU실패 | 초당 2~8회 (1~3%) | **0 (19줄 전부)** |
| 손상 | 0.71% | **0 (19줄 전부)** |
| 배수 | 4.8~177.6 | **0.4~1.0** |
| 타격음 | 발생 | **사라짐** |

**맞바꿈이 하나 생겼다.** `foc.c` 가 22kHz 를 고른 이유는 가청 대역 위라 조용해서였다.
5kHz 는 통신이 무결한 대신 모터에서 삐 소리가 난다. 지금 문제인 "탁탁" 과 새 "삐" 를
맞바꾼 상태다.

---

## 곁가지 발견

### 정방향/역방향 속도 비대칭 → **해결됨. [2026-07-27 정렬·지연 보상 일지](2026-07-27_align-lag-comp.md) 참조**

> 아래 원인 분석은 **틀렸다.** 코깅 편향이 아니라 **정지마찰 잔류 오차**였다.
> 실측 정방향/역방향 편차가 1.7° 뿐이라 코깅 몫은 0.85° 에 불과하다. 왕복 스윕이 효과를 낸 것은
> 편향을 평균내서가 아니라 회전자를 **끌고 지나가 정지마찰을 깨뜨렸기** 때문이다.
> 아래 "999Hz 에서는 지연이 18° 라 묻혔고" 라는 서술도 방향은 맞지만, 999Hz 대칭을
> 정렬이 정상이라는 근거로 읽은 것은 틀렸다(자세한 이유는 새 일지 §3).

| loop | 정방향 | 역방향 |
|---|---|---|
| 999Hz | +45 rad/s | −47 rad/s |
| 250Hz | +45 rad/s | **−14 rad/s** |
| 165Hz | (미측정) | **−6 rad/s** |

루프가 느려질수록 역방향만 무너진다. 원인은 **단방향 정렬이 남긴 오프셋 오차**로 본다.
코깅이 회전자를 붙잡는 방향이 진행 방향에 따라 반대라, 한 방향에서만 끌어와 재면
그 편향이 오프셋에 그대로 남는다. 이 오차는 커뮤테이션 지연과 한 방향에서는 더해지고
반대 방향에서는 상쇄된다. 999Hz 에서는 지연이 18° 라 묻혔고 250Hz 에서는 73° 라 드러났다.

**부팅마다 값이 달라진다.** 회전자가 어느 코깅 자리에 멈추느냐에 따라 정렬 기계각이
217.8° / 311.9° / 326.9° 등으로 바뀐다. 5kHz 확인 판에서는 정방향 +7.5 / 역방향 −40 으로
방향이 반대로 뒤집히기도 했다.

전기각을 0→2π→0 으로 왕복 스윕해 양 끝 오프셋을 단위벡터로 평균내면 상쇄된다
(이전에 구현했다가 이번 정리에서 되돌렸다. 실측 정방향/역방향 편차 3.4~6.4° 전기각).

### 센서가 MPU6050 이 아니다

```
MPU: 채널 0 : WHO_AM_I = 0x70
```

MPU6050 이면 `0x68` 이 나와야 한다. **`0x70` 은 MPU6500** 이다. GY-521 계열 모듈이
MPU6050 이름으로 팔리면서 실제로는 MPU6500/9250 이 올라간 경우가 흔하다.

지금 쓰는 레지스터(가속도·자이로 14바이트 버스트, `PWR_MGMT_1`)는 두 칩이 같아서
동작에는 문제가 없다. 문서·주석의 "MPU6050" 표기가 틀린 것이다.

### 초당 1회 로그 출력이 토크 충격을 만든다

`손상 0` 인 초의 `dt최대` 가 전부 **11~12ms** 였다. 그 초에서 가장 긴 루프가
**로그를 찍은 루프**라는 뜻이다.

로그 한 줄 약 190자, 115200 baud → `190 × 10 ÷ 115200 = 16.5ms`.
그동안 커뮤테이션이 완전히 멈춘다. 40 rad/s 면 회전자가 **전기각 175°** 를 나아가
90° 를 넘으므로 토크가 뒤집힌다.

**사용자가 "로그 뜰 때 토크 충격이 있는 것 같다" 고 관측한 것이 맞았다.**

---

## 손상이 짝으로 세어지는 이유 (재시도 실험이 틀린 이유)

손상 개수가 거의 항상 짝수였고 `MPU실패동시` 가 정확히 그 절반이었다(손상 48, 동시 23).

```
루프 N   : 엔코더가 쓰레기값 G 반환 → |G − 정상| 큼 → 손상 1회째 (MPU 실패와 동시)
           prev_angle = G          ← 비교 기준이 오염된다
루프 N+1 : 엔코더가 정상값 C 반환   → |C − G| 도 큼 → 손상 2회째 (MPU 는 정상)
           prev_angle = C          ← 복귀
```

**손상 하나가 큰 변화를 두 번 만든다.** 들어갈 때 한 번, 나올 때 한 번.
따라서 실제 손상 읽기는 24회이고 **그중 23회(96%)가 MPU 읽기 실패와 같은 루프**였다.

재시도 실험(#3)이 0/306 으로 실패한 것도 이 때문이다. 재시도한 값을 **이미 오염된
`prev_enc` 와 비교**하고 있었다. 두 번째 읽기가 정상값이어도 기준이 틀렸으니 크게 나온다.
**가설이 틀린 게 아니라 실험이 틀렸다.**

---

## 계측 설계에서 배운 것

### 1. 판정은 물리적으로 가능한 값과 비교해야 한다

```
최대변화 174.7도 (dt 4.0ms 설명가능 6.6도 = 26.6배)
```

"큰 값이 들어왔다" 만으로는 루프가 멈춰 실제로 많이 돈 것인지 값이 틀린 것인지 못 가린다.
**그 순간의 `dt` 와 휠속도를 같이 기록**하니 한 줄로 판정이 됐다.
전날 로그의 `튐 12` 같은 숫자는 이 비교가 없어 몇 판을 헤맸다.

### 2. 상한에 추정치를 쓰면 안 된다

처음엔 `2.5 × 휠속도추정 × dt` 를 상한으로 썼는데, 손상값이 그대로 속도 추정에 들어가
(**`휠 -69.7 rad/s`** 가 찍혔다. 3V 로는 불가능) 추정치를 오염시키고, 그 오염된 추정치가
다시 상한을 망가뜨렸다.

**고정 상한**으로 바꿨다. `80 rad/s × dt + 0.30rad`. 실측 최고가 50 rad/s 이므로
정상값은 절대 걸리지 않는다. 전날 교착에 빠졌던 것과 같은 함정의 변종이었다.

### 3. 루프 주기가 바뀌면 "초당 몇 회" 는 비교가 안 된다

400kHz 실험에서 루프가 480Hz 로 올라 읽기 횟수가 3배가 됐다. 손상 확률이 같아도
"1초에 한 번이라도 걸릴" 확률은 훨씬 높아져 **지표가 포화됐다.** 판정 불가였다.
이후 모든 카운터를 **루프당 %** 로 같이 찍었다.

### 4. 우회책은 계측을 오염시킨다

`SKIP_AFTER_FAIL` 로 실패 루프의 값을 버렸더니 `prev_angle` 을 갱신하지 않게 되고,
다음 비교가 여러 루프치 움직임을 담아 **정상 회전이 손상으로 세어졌다.**
손상 48 → 60 → 98 로 늘었는데 전부 내가 만든 값이었다. 우회하지 말고 원인을 잡아야 했다.

### 5. 부하를 끄고 재는 판이 결정적이었다

7번(모터 정지 버스 시험)이 방향을 완전히 바꿨다. 그전까지는 통신선에 붙은 장치들만
의심하고 있었는데, **모터를 끄니 10,002회 무결**이 나오면서 범위가 한 번에 좁혀졌다.
의심 대상을 빼는 것보다 **전부 끄고 하나씩 켜는** 쪽이 빨랐다.

---

## 이번에 배제된 것

- **루프 주기(커뮤테이션 갱신 주기)** — 250Hz 무음. 999Hz 와 차이 없음
- **커뮤테이션 지연으로 인한 토크 반전** — 전기각 73° 지연에도 무음
- **폐루프 커뮤테이션 자체** — 1단계 완전 무음, 손상 0
- **I2C 통신 속도** — 50k / 100k / 400k 에서 1.00 / 1.09 / 0.87%
- **mux 채널 전환** — 실패 0 (36줄 전부)
- **센서 무응답(NACK)** — 회전 중 0. 전부 시간 초과
- **엔코더 주소 0x06 이 버스를 교란** — 모터를 끄면 10,002회 무결
- **모터 전류** — 스위칭 0.77% → 전류까지 0.78%
- **값을 걸러내는 방식의 대응** — 임계값 조정 / 재시도 / 실패 루프 건너뛰기 전부 실패

전날까지 배제된 것: 과변조 / 시리얼 로그 / 기계적 결함 / 모터·코깅 / uq 변동 /
`LAG_COMP` / mux 채널 열림 / 버스 통신량 / 루프 멈춤 / 휠 속도 / 회전 방향

---

## 남은 일

1. ~~PWM 주파수 타협점~~ → **10kHz 확정** (커밋 `9e49173`).
   실측 손상률 22k 0.29% / 15k 0.53% / 12k 0.28% / 10k 0.00%
2. **로그 출력을 제어 루프 밖으로.** 초당 1회 전기각 175° 정지
3. ~~양방향 정렬 복원~~ → **해결** (커밋 `5a90dd1`, [일지](2026-07-27_align-lag-comp.md))
4. 3단계(밸런싱 제어), 4단계(텔레메트리)
5. 문서·주석의 "MPU6050" → MPU6500 정정

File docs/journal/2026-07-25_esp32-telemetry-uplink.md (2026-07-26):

# 2026-07-25 : ESP32 → 서버 텔레메트리 송신 + 시리얼 로그 미러링 구현

더미 데이터로 검증해 둔 서버·웹에 실제 ESP32 센서값을 연결하고, 시리얼 로그까지 웹에서 보게 만들었다. 설계 의도와 도중에 막힌 지점을 기록한다.

---

## 결과

- ESP32가 WiFi STA로 붙어 WebSocket 클라이언트로 `/ws/esp` 에 30Hz 송신.
- 서버는 받은 프레임을 기존 `TelemetrySink` 로 그대로 흘려 대시보드에 브로드캐스트.
- `DashboardWebSocketHandler` / `SensorFrame` / 차트 코드는 **한 줄도 안 바뀜**. 생산자만 더미 → 실기기로 교체.
- `ESP_LOGx` 출력을 가로채 같은 소켓으로 보내 웹 대시보드에서 시리얼 로그 확인 가능. USB 없이 디버깅.

관련 커밋:
| | |
|---|---|
| `65cb7b2` | feat: ESP32 센서 데이터 서버 실시간 송신 구현 |
| `935f689` | fix: 엔코더 각도 도/라디안 혼용 수정 완료 |
| `6fcd8bf` | feat: ESP32 시리얼 로그 웹 대시보드 미러링 구현 |

---

## 설계 결정

### 코어 분리 (core0 제어 / core1 통신)

`app_main` 은 `CONFIG_ESP_MAIN_TASK_AFFINITY_CPU0` 로 core0 고정인데, WiFi 태스크와 lwIP TCP/IP 태스크는 **기본이 core0** 이다. 그대로 두면 1kHz 제어 루프와 CPU를 다툰다.

`sdkconfig.defaults` 에 두 줄 추가:
```
CONFIG_ESP_WIFI_TASK_PINNED_TO_CORE_1=y
CONFIG_LWIP_TCPIP_TASK_AFFINITY_CPU1=y
```

주의: 처음에 `CONFIG_ESP_WIFI_TASK_CORE_ID_1` 로 썼다가 `unknown kconfig symbol` 경고. IDF 5.5 의 실제 심볼명은 `ESP_WIFI_TASK_PINNED_TO_CORE_1`.

**이것만으로는 부족하다.** 전송 호출 자체가 core0(제어 루프)에서 나면 WiFi 드라이버만 core1로 옮겨봐야 소용없다. 그래서 전송 태스크를 만들어 `xTaskCreatePinnedToCore(..., 1)` 로 고정.

### 길이 1 큐 + xQueueOverwrite

제어 루프가 네트워크 I/O로 블록되면 로봇이 넘어진다. 큐 길이를 1로 두고 `xQueueOverwrite` 로 덮어쓰기만 한다.

- 제어 루프 대기 시간 0 (큐가 차 있어도 실패하지 않음).
- 전송이 밀려도 오래된 프레임이 쌓이지 않는다. 최신 것만 살아남음.

### TELEMETRY_ENABLED 컴파일 토글

런타임 `if` 가 아니라 `#define` + `#if` 로 뺀 이유: 0 일 때 제어 루프 기계어가 통신 도입 전과 동일해진다. 밸런싱 튜닝 중 주기 흔들림의 원인 후보에서 통신을 완전히 배제할 수 있다.

### JSON은 snprintf

cJSON을 안 쓴 이유: 프레임 모양이 고정이라 포맷 문자열 하나로 끝난다. 의존성 0, 할당 0.

`isfinite()` 검사를 넣었다. `angle`/`uq` 가 nan 이면 snprintf가 `nan` 을 뱉는데 이건 유효한 JSON이 아니라 **서버가 프레임을 통째로 버린다**. 화면만 조용히 멈추는 형태라 원인 추적이 매우 어렵다.

### 전송 주기는 시간 기준

처음엔 "제어 루프 30 사이클마다" 였는데, 루프 실제 주기가 1kHz가 아니면 송신 레이트가 같이 흔들린다. `esp_timer` 기준 33000us 간격으로 바꿈.

### 로그 미러링 — 후킹은 큐에 넣기만

`esp_log_set_vprintf()` 로 `ESP_LOGx` 를 가로채되, **콜백 안에서는 큐에 복사만** 한다. 시리얼 출력은 그대로 유지.

- 이 콜백은 WiFi·lwIP 내부를 포함한 **아무 태스크에서나** 불린다. 블록하면 안 된다 (`xQueueSend` timeout 0, 넘치면 버림).
- 콜백에서 직접 WS 전송을 하면 **무한 재귀**에 빠진다. 전송이 실패하면 에러 로그를 찍고, 그 로그가 다시 전송을 부른다.
- 같은 이유로 드레인에도 상한(`LOG_DRAIN_MAX`)을 뒀다. 전송이 로그를 유발하면 큐가 계속 다시 채워져 루프를 못 빠져나간다.
- `CONFIG_LOG_VERSION=1` 전제 (한 줄 = 콜백 1회). v2로 올리면 줄이 조각나 이 가정이 깨진다.

**미연결일 때 로그 큐를 비우지 않는다.** 처음엔 `xQueueReset` 으로 비웠는데, 그러면 WS 연결 전에 나오는 센서·모터 초기화 로그가 전부 사라진다. `telemetry_start()` 를 `app_main` 맨 앞에 둔 의미가 없어진다. 큐 길이를 48로 늘리고 쌓아뒀다가 연결 직후 한꺼번에 올린다.

### 한 소켓, 두 종류

로그를 별도 엔드포인트로 빼지 않고 `/ws/esp` 하나로 보낸다. 서버는 `{"log":` 접두사로 가른다.

트리(`readTree`)로 판별하지 않은 이유: 30Hz로 들어오는 텔레메트리를 두 번 파싱하게 된다. 송신 측 포맷을 서버가 쥐고 있으니 접두사 비교로 충분하다.

---

## 막혔던 지점

### 1. ESP는 WiFi에 붙는데 서버 연결만 실패

```
E transport_ws: Error connecting to host 192.168.0.2:8080
errno=119 (CONNECTION_TIMEOUT)
```

방화벽을 의심했으나 아니었다. 실제 원인은 **서브넷 분리**:

| | IP | 게이트웨이 |
|---|---|---|
| ESP32 (WiFi) | 192.168.45.66 | 192.168.45.1 |
| PC (유선) | 192.168.0.2 | 192.168.0.1 |

판별 방법: PC에서 `tracert 8.8.8.8` 했을 때 hop2가 `118.218.75.1`(ISP 공인망)이었다. PC 공유기가 WiFi 공유기 밑에 물려 있었다면 hop2가 `192.168.45.1` 로 찍혔어야 한다. → 두 장비가 **서로 다른 회선**.

집에 공유기가 2대였고 ESP가 다른 쪽 SSID에 붙어 있었다. 같은 공유기 SSID로 바꾸니 해결.

**교훈: 연결 안 될 때 방화벽부터 보지 말고 양쪽 IP 대역부터 비교할 것.**

### 2. 엔코더 각도가 20267~20625 로 표시

`encoder.c` 의 단위 혼용 버그:
```c
*angle_rad = 360.0f - (float)raw * ((2.0f * M_PI) / 16384);
```
360(도)에서 라디안을 빼고 있었다. 반환값이 353.7~360 이고, 이걸 라디안으로 보고 ×57.2958 하니 20265~20626.

**FOC가 지금까지 멀쩡했던 이유:** `foc_apply_torque` 가 `POLE_PAIRS * (now_angle - align_angle)` 형태로만 쓴다. 두 값에 똑같이 상수 360이 들어가 차분에서 상쇄된다. 그래서 각도를 화면에 표시하기 전까지 드러나지 않았다.

`2π` 로 고쳐도 차분은 동일 → **밸런싱 튜닝값 그대로 유효**.

### 3. 센서값이 0 / −1 로만 보임

프론트가 `fmt(s[k], 0)` — 소수점 0자리였다. 원래 raw int16(±16384) 기준으로 쓴 코드인데 물리단위(g, deg/s)로 바꿔 보내면서 `0.012 g` 가 ` 0` 으로 뭉개졌다. 가속도 3자리 / 각속도 1자리로 분리.

**교훈: 와이어 단위를 바꾸면 표시 자릿수도 같이 봐야 한다.** 데이터는 정상인데 화면만 이상해서 펌웨어를 한참 들여다봤다.

### 4. ESP-IDF 빌드 환경

`export.ps1` 이 py3.14 가상환경을 찾는데 실제 설치된 건 py3.11. 매번 앞에 붙여야 함:
```powershell
$env:IDF_PYTHON_ENV_PATH="C:\Espressif\python_env\idf5.5_py3.11_env"
. C:\Espressif\frameworks\esp-idf-v5.5.4\export.ps1
```

### 5. 빌드는 성공하는데 로그가 안 뜸 — ninja mtime 함정

시리얼 로그를 한 번 되돌렸다가 백업에서 복원했는데, 재플래시·서버 재시작을 해도 로그가 안 떴다.

코드는 다 맞았다. 서버 라우팅은 테스트로 검증했고(`EspIngestHandlerTest`), 서빙되는 `app.js`/`index.html` 도 최신이었다. 문제는 **펌웨어 바이너리에 로그 코드가 아예 없었던 것**.

```
telemetry.c        mtime 11:16:39   ← 복원된 소스
telemetry.c.obj    mtime 11:22:25   ← 기존 오브젝트
```

PowerShell `Copy-Item` 은 원본 파일의 `LastWriteTime` 을 **보존**한다. 백업에서 복원한 소스의 mtime이 기존 오브젝트보다 오래돼서, ninja가 "이미 최신"으로 판단하고 **재컴파일을 건너뛰었다**. 링크는 옛 오브젝트로 수행됐다.

빌드는 `Project build complete` 를 정상 출력하고 바이너리 크기까지 찍었다. 실패 신호가 전혀 없었다.

**판별 방법:** 산출물에서 마커 문자열을 직접 찾는다.
```bash
grep -q '{"log":"' build/esp.bin && echo 있음 || echo 없음
```
`없음` → 컴파일 안 됨. touch 후 재빌드하니 `telemetry.c.obj` 가 다시 컴파일되고 바이너리가 512B 늘었다.

**교훈: 파일을 복사해서 되돌린 뒤에는 "빌드 성공"을 믿지 말고 산출물에 반영됐는지 확인할 것.** 복원 직후 `touch` 하거나 `idf.py fullclean` 하는 게 안전하다.

---

## 검증

- `SensorFrameParseTest` — 펌웨어 `build_json` 이 만드는 문자열을 그대로 넣어 `SensorFrame` 파싱을 고정. 이 계약이 깨지면 서버가 프레임을 조용히 버리므로 테스트로 못박음.
- `EspIngestHandlerTest` — 텔레메트리와 로그가 각각 `publish` / `publishLog` 로 가는지 고정. 위 5번 디버깅에서 서버 라우팅을 용의선상에서 빼는 데 썼다.
- 실기기 연결 후 대시보드에서 angle/rate/uq 차트, 센서 3개, 엔코더 각도, 시리얼 로그 전부 정상 확인.

---

## 미결

- `voting`/`fault` 는 FR-2(결함 시뮬레이션) 구현 전이라 `ok`/`none` 고정. 스키마만 채운 상태.
- 프레임률·드롭률 실측 안 함. `TELEMETRY_INTERVAL_US` 는 33000(30Hz) 잠정.
- MPU 3개를 매 사이클 전부 읽도록 바꿨다. I2C 트랜잭션이 3배가 되므로 **제어 루프 실주기 재측정 필요**. 밀리면 `I2C_FREQ_HZ` 400kHz 승격 검토 (MPU6050·TCA9548A·MT6701 모두 지원).
- 로그 큐가 넘치면 **최신 줄을 버린다**(`xQueueSend` 실패). 오래된 줄을 버리는 링 방식이 모니터 의미상 맞지만, 후킹 콜백에서 큐를 pop 하려면 버퍼가 더 필요해 보류. 부팅 버스트는 48줄로 커버됨.
- 로그 후킹 설치 시점에 아주 좁은 경쟁 구간이 있다. `s_prev_vprintf = esp_log_set_vprintf(...)` 에서 훅은 함수 진입 즉시 활성화되는데 대입은 반환 후다. 그 사이에 다른 태스크가 로그를 찍으면 NULL 함수 포인터 호출. 실제로 밟은 적은 없다.
- `docs/server.md` 의 §10「ESP32 연동 시 변경점」·§12 미결사항이 아직 연동 전 기준 → 갱신 필요.

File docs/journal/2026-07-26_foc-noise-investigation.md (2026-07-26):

# 2026-07-26 : FOC 커뮤테이션 소음 추적 (진행중)

> **상태: 미해결.** 원인 후보가 두 갈래로 좁혀졌고 다음 테스트가 정해져 있다.
> 이어서 할 때는 §다음 테스트 부터 보면 된다.

---

## 증상

밸런싱 구동 중 모터에서 **"탁탁탁" 타격음과 진동**. 밸런싱이 잠시 버티다 넘어지는 것과
같이 나타났으나, 추적 결과 **두 증상은 별개**로 보인다(소음은 고정 uq 로 돌려도 난다).

- 정지 상태(전류 O, 회전 X): **무음**
- 관성 코스팅(전류 X, 회전 O): **무음**
- 전원 끄고 손회전: **무음**
- **역방향(uq<0)에서 훨씬 심하다**

## 확정된 실험 행렬 ★ 가장 중요

| 조건 | 커뮤테이션 | uq | loop | 결과 |
|---|---|---|---|---|
| 오픈루프, 80 rad/s | 내부 적분 | 고정 | 999Hz | **무음** |
| 고정토크, 47 rad/s | **엔코더** | 고정 | 999Hz | **무음** |
| 고정토크, 37 rad/s | **엔코더** | 고정 | **235Hz** | **소음 (역방향)** |
| 밸런싱 | 엔코더 | 제어기 | 235Hz | 소음 |

**2행과 3행의 코드 차이는 "루프에서 MPU 를 읽느냐" 하나뿐이다.** 그런데 그게 두 가지를
동시에 바꾼다:

- **(a) 루프 주기** 999Hz → 235Hz. 커뮤테이션 지연이 전기각 15° → **63°**
  (`전기각속도 = 휠속도 × 극쌍수 7`, 37 rad/s → 259 rad/s, × 4.25ms = 1.10rad)
- **(b) I2C 버스** 엔코더 단독 → mux 전환 + MPU 트랜잭션이 끼어듦

같이 딸려온 미해석 데이터:

```
999Hz : 튐 0,    최대변화 5.3°
235Hz : 튐 다수, 최대변화 최대 178°
```

**MPU 가 버스에 끼어드는 순간 엔코더 데이터 품질이 무너진다.**

---

## 배제된 가설

| 가설 | 검증 방법 | 결과 |
|---|---|---|
| 루프 주기 부족(120Hz) | 센서 읽기 축소 → 240Hz | ✗ 변화 없음 |
| 전압 과변조 | `UQ_LIMIT` 11V → 5V | ✗ |
| 시리얼 로그 UART 블로킹 | 루프 내 `ESP_LOGI` 제거 | ✗ |
| 기계적 결함 | **관성 코스팅** (회전 유지·전류 제거) | ✗ **확실히 배제** |
| 모터 자체(코깅·자석) | 오픈루프 80 rad/s | ✗ 배제 |
| 엔코더 읽기 실패 | `enc_fail` 계측 | ✗ 항상 0 |
| uq 변동(데드밴드·자이로) | 고정 uq 대조군 | ✗ 소리 남 |
| 커뮤테이션 지연 | 각도 외삽 보상(`LAG_COMP`) | ✗ |
| 엔코더 값 손상 | 이상값 필터 + 외삽 대체 | ✗ |

### 부분 성공: 정렬 오차 ε

**정/역 최고 속도 비대칭은 해결됐다.** 소음은 남았다.

- 원인: 단방향 정렬은 코깅 디텐트가 회전자를 붙잡는 편향을 그대로 오프셋에 남긴다.
- 실측 **정/역 편차 12.6° 전기각** → 기존 단방향 정렬은 약 6.3° 틀어져 있었다.
- ε 이 있으면 uq 부호에 따라 d축 성분 부호가 뒤집혀(약계자/증자) 한 방향만 속도가 안 붙는다.
- 해결: 전기각 0→2π→0 왕복 스윕 후 양 끝 오프셋을 단위벡터 평균 (`foc_align`).

---

## 남은 가설

### A. MPU I2C 타임아웃으로 루프가 간헐 정지 (가장 유력)

```c
mpu6050_read_accel_gyro(MUX_CHANNELS[0], ...);   // 반환값을 무시하고 있다
```

`I2C_TIMEOUT_MS = 10`. 읽기가 타임아웃하면 루프가 10ms 멈추고 그동안 **전기각이 얼어붙는다** → 탁.

`최대변화 178°` 도 손상이 아니라 **긴 정지 뒤의 정상 회전**일 수 있다:
`37 rad/s × 85ms = 3.1rad = 178°` (`angle_delta` 가 ±180° 로 접는다).

평균 235Hz 는 유지되면서도 초당 몇 번의 큰 정지는 숨을 수 있다.
**현재 코드에 최악 루프 시간(`dt_max`) 계측이 없다.**

### B. mux 채널이 열린 채로 엔코더를 읽는다

`mux_select()` 후 채널이 계속 열려 있어 하위 MPU 가 버스에 매달린 상태로 MT6701 을 읽는다.

덧붙여 **MT6701 의 주소 0x06 은 I2C 예약 대역(0x00~0x07)** 이다. 0x04~0x07 은 규격상
Hs-mode 마스터 코드라 버스의 다른 장치가 다르게 해석할 여지가 있다. 엔코더 단독일 땐
멀쩡하다가 mux/MPU 가 붙으면 나빠지는 정황과 맞는다.

### C. 내부 풀업만 사용

```c
.sda_pullup_en = true,   // ESP32 내부 풀업 ≈ 45kΩ
```

I2C 표준은 2.2k~10k. 45kΩ 는 매우 약해 배선·정전용량이 늘면 상승 시간이 규격을 벗어난다.
하드웨어 변경 없이는 직접 못 고치지만, `I2C_FREQ_HZ` 를 **낮춰서**(50kHz) 나아지면
신호 품질 문제라는 간접 증거가 된다.

### D. 움찔거림이 `LAG_COMP` 때문일 가능성

역방향에서 회전 없이 움찔거리기만 하는 증상. `LAG_COMP` 도입 후 나타났고 교착 버그를
고친 뒤에도 남았다. **보상 자체가 원인인지 미확인.**

---

## 다음 테스트 (여기서 재개)

### 0. `LAG_COMP = 0` — 가장 쌈

움찔거림이 내가 넣은 보상 때문인지 원래 있던 건지부터 가른다. 증상이 두 개인데 하나가
인공물이면 판단이 흐려진다.

### 1. 루프 주기 vs 버스 트래픽 분리 ★ 핵심

**MPU 읽기 대신 순수 지연**을 넣어 999Hz 를 235Hz 로 낮춘다. I2C 트래픽은 엔코더만 남는다.

```c
esp_rom_delay_us(3250);   // MPU 읽기 자리에
```

| 결과 | 결론 |
|---|---|
| 소음 발생 | **(a) 루프 주기**가 원인. 지연 보상이 왜 안 들었는지 재검토 |
| 무음 유지 | **(b) I2C 버스 트래픽**이 원인. A/B/C 로 진행 |

999Hz 가 조용했다는 사실이 있으므로 반드시 한쪽으로 갈린다. **정보량이 가장 크다.**

### 2. 계측 보강 (flash 왕복 절약을 위해 1과 같이)

- **최악 루프 시간 `dt_max`** ← 정지를 직접 잡는다
- **8ms 초과 루프 횟수** ← 정지 빈도
- **MPU 읽기 실패 횟수** ← 지금 무시 중인 반환값
- 엔코더 실패/튐/최대변화 (기존 유지)

`dt_max` 가 20ms 이상 찍히고 MPU 실패가 세어지면 **A 확정**.

### 3. 원인별 대응

- **A** → `I2C_TIMEOUT_MS` 축소, 실패 시 이전값 유지, `I2C_FREQ_HZ` 400kHz
- **B** → 엔코더 읽기 전 mux 닫기(0x00 기록). 소프트웨어만으로 검증 가능
- **C** → `I2C_FREQ_HZ` 를 50kHz 로 낮춰 나아지는지 확인

### 4. 소음과 무관하게 확실한 개선

- `I2C_FREQ_HZ` 100k → **400k** (MPU6050·TCA9548A·MT6701 모두 지원). 14바이트 전송 1.5ms → 0.38ms
- `MUX_SETTLE_US` 500 → 150 (실측으로 하한 탐색)
- → 루프 235Hz → 500Hz 이상 기대. **MPU 읽기 하나가 루프의 76%(3.25ms)를 먹고 있다.**

---

## 현재 코드 상태

### 실행 모드 (`main.c`)

```c
#define RUN_MODE  MODE_TORQUE   // MODE_BALANCE / MODE_OPENLOOP / MODE_TORQUE
```

| 모드 | 내용 |
|---|---|
| `MODE_BALANCE` | 정상 밸런싱 |
| `MODE_OPENLOOP` | 엔코더 미사용. 전기각 내부 적분. 속도 20/30/40 스윕(현재 40/60/80) |
| `MODE_TORQUE` | **밸런싱 루프에서 uq 만 고정**(5초마다 부호 반전). 다른 건 전부 동일한 대조군 |

**세 모드 모두 빌드 확인됨(경고 0).** 되돌릴 때 `MODE_BALANCE` 로.

### 현재 계측 (1초 주기 로그)

```
loop 235Hz  휠 37.2 rad/s  실패 0  튐 12  최대변화 25.97도  uq +0.0~+3.0
```

### 주요 튜너블

| 위치 | 상수 | 현재값 | 비고 |
|---|---|---|---|
| `main.c` | `I2C_FREQ_HZ` | 100000 | 400k 승격 후보 |
| `main.c` | `LAG_COMP` | 1.0 | 0 으로 두면 보상 없음 |
| `main.c` | `ENC_JUMP_RAD` | 1.0 | **속도 추정치로 만들지 말 것**(아래 교훈) |
| `main.c` | `TELEMETRY_INTERVAL_US` | 100000 | 10Hz |
| `mpu6050.c` | `MUX_SETTLE_US` | 500 | 축소 후보 |
| `mpu6050.c` | `I2C_TIMEOUT_MS` | 10 | 정지 시간의 하한을 정함 |
| `balance.c` | `BAL_K1 / BAL_K2` | −2.0 / −0.4 | 미튜닝 |
| `balance.c` | `UQ_LIMIT` | 5.0 | 선형 변조 한계 `V_SUPPLY/2 = 5.65V` 안 |
| `balance.c` | `TILT_CUTOFF` | 30.0 | |
| `balance.c` | `DEADBAND` | 1.0 | 0 테스트 미실시 |

---

## 테스트 설계에서 틀린 것들 (반복 방지)

1. **오픈루프 테스트가 두 변수를 동시에 바꿨다** — 커뮤테이션 소스뿐 아니라 uq 도 고정으로
   바뀌었다. 뒤늦게 `MODE_TORQUE`(uq 만 고정)로 대조군을 다시 만들었다.
2. **`MODE_TORQUE` 초판도 두 변수를 바꿨다** — MPU 를 안 읽어 루프가 999Hz 로 올라갔다.
   밸런싱 루프 안에서 uq 한 줄만 바꾸는 형태로 고쳤다.
3. **"손회전 무음 → 기계적 원인 배제"는 속도를 통제하지 못했다** — 기계적 힘은 대체로 ω² 에
   비례한다. 손회전 0.5회전/초 vs 구동 2.4회전/초는 힘이 23배 차이다. 관성 코스팅
   (회전 유지·전류만 제거)이 올바른 통제였다.
4. **이상값 임계값을 추정치로 만들어 교착을 만들었다** — `limit = wheel_vel × dt × k` 인데
   `wheel_vel` 은 통과된 샘플에서만 갱신된다. 한 번 거부가 시작되면 영원히 거부된다.
   실제로 휠이 23.5 rad/s 를 넘는 순간 전 샘플이 거부돼 전기각이 얼어붙었고,
   손으로 휠을 돌려 얼어붙은 각도 근처를 지나야만 복구됐다.
   **추정치로 그 추정치의 갱신 조건을 판정하면 안 된다. 초기값을 대입해 볼 것.**
5. **소리를 귀로 세는 계측은 신뢰도가 낮았다** — 1.47회/회전 → 1.05회/회전 → 초당 고정 등
   측정마다 결론이 뒤집혔다. 가속 구간에서는 "회전당 횟수"가 정의되지 않는다.

---

## 이 세션에서 같이 한 다른 작업

### 구조 정리 (완료, 미커밋)

- **`telemetry` 를 `main/` 에서 `components/telemetry/` 로 이동.** 설정 주입 방식
  (`telemetry_start(&cfg)`)이라 component 가 `secrets.h` 에 의존하지 않는다.
  `main/CMakeLists.txt` 의존성에서 `esp_wifi esp_netif esp_event nvs_flash spi_flash` 제거.
- ESP-IDF hello_world 템플릿 잔재 삭제: `pytest_hello_world.py`, `sdkconfig.ci`, `.devcontainer/`
- `esp/README.md` 재작성 (구조·빌드·`IDF_PYTHON_ENV_PATH` 우회·ninja mtime 주의)
- `app_main` 분해: `i2c_bus_init` / `align_rotor` / `calibrate_gx_bias` / `calibrate_setpoint`
  / `publish_frame` / `balance_loop`
- 매직 인덱스 → `enum { AX, AY, AZ, GX, GY, GZ, AXIS_N }`
- `MPU6050_ACCEL_LSB_PER_G` / `MPU6050_GYRO_LSB_PER_DPS` 를 `mpu6050.h` 로
  (`mpu6050_init` 은 레인지를 설정하지 않고 리셋 기본값 ±2g/±250°/s 를 쓴다)
- 미사용 API 주석 처리: `mpu6050_read_accel`, `foc_closeloop_velocity`
- `esp/sample/` → `reference/arduino/` (IDF 프로젝트 루트 밖으로)
- 주석 전반 정리 (코드를 반복하는 주석 제거, 남길 것은 "왜"만)

### 안전 조치 적용

- **캘리브레이션 중 모터 끄기** — 정렬 d축 전압을 2.6초간 물고 있던 것을 `foc_enable(false)` 로 끊음

### 07-23 일지 정정

**드라이버 고장이 아니라 배터리 전압 저하였다.** 같은 드라이버로 이후 작업을 정상 진행했다.
`V_SUPPLY` 가 11.3f 하드코딩이라 배터리가 닳으면 같은 uq 명령이 더 낮은 전압으로 인가되고,
그래서 토크가 "점점" 약해진다. 튜닝 재현성도 깨진다.
→ `UQ_LIMIT ≤ 4V` 안전조치는 취소(원인이 과전류가 아니었음).

---

## 미결 (소음과 별개)

- 밸런싱 튜닝 자체: `DEADBAND 0` 테스트, K2 위주 튜닝, 적분항/휠속도항(K3) 미검토
- **휠 속도항(K3) 부재** — 리액션 휠 도립진자는 상태가 셋(기울기·기울기 각속도·**휠 속도**)인데
  둘만 쓴다. 휠이 한 방향으로 가속만 하다 역기전력으로 토크가 고갈된다.
  엔코더로 이미 `wheel_vel` 을 계산하고 있으니 하드웨어는 불필요.
- **토크 예산 미계산** — `중력토크 = m·g·L·sin(θ)` 와 모터 최대토크를 비교한 적이 없다.
  복원 가능 각도가 몇 도인지 모른다. 로봇 질량·무게중심 높이 필요.
- **상보필터 계수가 루프 주기에 종속** — `COMP_ALPHA` 가 고정값 0.98 이라 시정수 `α·dt/(1−α)`
  가 dt 에 비례한다. 루프 주기를 바꾸면 필터 특성이 같이 변해 튜닝이 흔들린다.
  고정 시정수 기준 `α = τ/(τ+dt)` 로 바꿔야 한다.
- `GYRO_LSB_PER_DPS` 가 `balance.c` 에 중복 (mpu6050.h 매크로와 별개)
- 로그 후킹 설치 시점의 좁은 경쟁 구간 (`s_prev_vprintf` 대입 전 NULL 호출 가능)
- `docs/server.md` §10·§12 가 ESP32 연동 전 기준 → 갱신 필요. 송신 주기도 30Hz → 10Hz 로 변경됨
- 이 일지 파일명이 내용과 어긋남: `2026-07-23_balance-tuning-driver-fault.md`
  → `..._battery-sag.md` 로 변경 검토

## 미커밋 상태

구조 정리·정렬 수정·계측 추가가 전부 워킹트리에만 있다. 신규 추적 대상:
`docs/journal/2026-07-25_*.md`, `docs/server.md`, `docs/면접-준비.md`,
`esp/components/telemetry/`, `reference/`

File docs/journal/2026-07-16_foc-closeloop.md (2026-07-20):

# 2026-07-16 : FOC 클로즈루프 구현

### 문제 1. foc 정렬 과정
- 시도: 클로즈루프 로직 구현 후 동작 테스트
- 증상/원인: 전압은 인가되나, 제자리에서 떨림 문제
- 이유: encoder 값이 증가하는 방향과 모터 전기각이 반대
- 해결: encoder_read_angle이 계산하는 방향을 반대 방향으로 구현

### 문제 2. i2c 버스 충돌 문제 
- 증상: mpu6050
```
E (441401) i2c.master: I2C software timeout
W (441401) i2c.common: GPIO 16 is not usable, maybe conflict with others
W (441401) i2c.common: GPIO 17 is not usable, maybe conflict with others
```
- 원인: 
- 해결:

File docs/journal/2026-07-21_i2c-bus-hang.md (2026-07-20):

# 2026-07-21 : I2C 버스 멈춤 → 워치독 리셋 해결 (레거시 드라이버 이관)

밸런싱 통합 테스트 중, 모터 동작 시 I2C가 멈추며 재부팅되는 문제를 추적·해결한 기록.

---

## 증상
```
W i2c.common: GPIO 16/17 is not usable, maybe conflict with others
rst:0x7 (TG0WDT_SYS_RESET)
WDT rst info: PRO CPU PC=... _xt_lowint1   ← CPU0가 인터럽트에 갇힘
```
- 워치독 리셋(brownout 아님). CPU0가 인터럽트 처리 중 갇혀 워치독이 강제 리셋.
- "GPIO not usable" 경고는 원인이 아니라 결과 (I2C timeout 후 드라이버 버스복구 시 GPIO 재설정).
- 가끔 즉시, 가끔 한참 뒤 → 확률적.

## 진단 과정

### 1. 범인 격리
| 구성 | 결과 |
|---|---|
| foc+encoder+mpu 다 주석 | 정상 |
| foc(모터) 주석, encoder+mpu | 리셋 |
| foc+encoder, **mpu만 주석** | **정상** |
→ 범인은 **MPU(mux) I2C 경로**.

### 2. mux 전환이 방아쇠
- `mpu6050_read_accel`이 매 호출 `mux_select`(0x70 쓰기) 수행.
- mux를 루프 전 1회만 선택 → 리셋 사라짐 → **반복 mux 쓰기가 버스 글리치 유발**.

### 3. 전원/모터 상관 → PWM 스위칭 EMI 확정
- 배터리 OUT(드라이버 전원X): 경고만, 계속 동작.
- 배터리 IN: 리셋. 단 **모터 기계적 회전과 무관** (안 돌아도 리셋, 돌아도 멀쩡할 때 있음).
- **FOC 완전 주석(PWM 스위칭 없음) → 리셋 전혀 안 남.**
- → 진짜 방아쇠는 **드라이버 22kHz PWM 스위칭 EMI**. 확률적으로 I2C 트랜잭션과 겹칠 때 버스 오염.

### 4. 하드웨어는 이미 양호
- 배터리(-) 진짜 스타 그라운드(SimpleFOC/스텝다운 각각 분기), SimpleFOC 전원부 1000µF 벌크 캡.
- 모터 3상선 독립 핀. I2C 10cm(단면 만능기판, 못 줄임).
- 100kHz로 낮춰도 동일 → 엣지속도/풀업 마진 문제 아님.

### 5. 결정적 단서 — 아두이노는 같은 HW에서 됐음
- 동일 하드웨어(mux+3MPU+MT6701, I2C 16/17)로 **아두이노에선 3센서 평균+모터 동시 동작 정상**(진동·리셋 없음).
- 옛 커밋의 남의 참조코드는 MT6701을 ABZ로 쓴 다른 구성이었지만, 본인 아두이노 코드는 같은 무거운 I2C 구성이었음.

## 근본 원인
**ESP-IDF 새 `i2c_master` 드라이버가 노이즈로 stuck된 버스에서 CPU를 인터럽트에 가둠 → 워치독 리셋.**
- 글리치(EMI)는 아두이노에도 있었으나, **아두이노 Wire는 stuck 시 타임아웃 후 넘어감**(CPU 안 멈춤).
- ESP32 Arduino Wire는 내부적으로 **ESP-IDF 레거시 i2c 드라이버(`driver/i2c.h`) 기반** → 이게 견딘 이유.
- 즉 하드웨어 EMI 문제이자, **새 드라이버가 글리치에 취약한** 문제.

## 해결 — 레거시 `driver/i2c.h`로 이관
- `i2c_new_master_bus`/디바이스 핸들 → `i2c_param_config` + `i2c_driver_install` + 포트 직접 접근.
- 읽기/쓰기: `i2c_master_write_to_device`, `i2c_master_write_read_device`.
- 버스 stuck 시 **CPU 행 없이 `ESP_ERR_TIMEOUT` 반환** → 그 샘플만 버리고 이전값 유지로 계속.
- 대상: `main.c`, `mpu6050.c/.h`, `encoder.c/.h`, 각 CMakeLists(`esp_driver_i2c`→`driver`).
- 유지: mux 전환 후 settle 500µs, 실패 시 이전값 유지, voting 준비.
- 참고: 레거시 API는 v5.5에서 deprecated 경고(빌드는 정상). 새 드라이버 CPU 행 이슈 회피 목적.

## 시도했으나 부족했던 것 (기록용)
- settle 지연 추가 / 이전값 유지 → 배터리 OUT은 견디나 IN(스위칭)은 여전히 리셋.
- 실패 시 `i2c_master_bus_reset` 통제 복구 → 행이 드라이버 콜 내부에서 나 도달 못 함.
- `I2C_TIMEOUT_MS` 100→10 → 호출이 타임아웃 무시하고 행 → 무효.
- → 전부 새 드라이버 한계. 드라이버 교체가 정답이었음.

## 곁다리로 잡은 버그 (별도 커밋)
- FOC 첫 iteration `uq` 폭발: `main.c` `prev_angle` 실제값 초기화 + `uq` ±V_SUPPLY 클램프.
- `uq: nan`: `dt=0`일 때 `0.0f*inf=nan` (balance.c의 KD항) → 루프 전 delay로 첫 dt 0 방지.

## 검증
- 빌드 성공(경고만), 실기 테스트 **리셋 이상 무**. I2C 문제 종료.

---

## 남은 문제 (다음 작업)
1. **반응 0.1초 지연 → 넘어짐** : 자이로(각속도) 미사용. `mpu6050_read_accel`이 가속도만 읽고 자이로(0x43) 안 읽음. balance는 가속도 raw만 P제어(KD=0). → 자이로 추가(상보필터+각속도항) 또는 아두이노식 상태피드백(토크모드) 필요.
2. **양수 uq에서만 진동/소음** : FOC 커뮤테이션 비대칭. 극쌍수/정렬 오프셋/인코더 방향 의심. 오픈루프 양방향 테스트로 원인 격리 예정.

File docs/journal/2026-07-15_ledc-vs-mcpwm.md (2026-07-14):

# 작업 일지 - 2026-07-15 : FOC PWM 페리페럴 선택 (LEDC vs MCPWM)

맨땅 FOC 구현(`components/foc/`)에서 3상 PWM을 무엇으로 만들지 결정한 기록.
결론: **LEDC 채택.**

## 배경

ESP32는 PWM 발생 페리페럴이 두 개다.

| | LEDC | MCPWM |
|---|---|---|
| 원래 용도 | LED 디밍 | Motor Control PWM |
| 데드타임 | 없음 | 있음 (하이/로우 동시 도통 방지) |
| 상보(complementary) 출력 | 없음 | 있음 (6-PWM) |
| 구현 난이도 | 쉬움 | 복잡 |

이름만 보면 모터엔 MCPWM이 정석이다. 그런데도 LEDC를 골랐다.

## 선택 근거

### 1. 드라이버가 3-PWM 입력이다
- SimpleFOC Mini = **DRV8313** 기반 **3-PWM** 게이트 드라이버.
- 우리는 IN1/IN2/IN3에 신호 **3개만** 주면 된다.
- 하이/로우 게이트 스위칭과 **데드타임은 드라이버 칩이 내부에서 처리**한다.

### 2. MCPWM의 강점이 여기선 불필요
- MCPWM의 핵심 이점 = 데드타임 + 6-PWM 상보 출력.
- 이건 게이트 6개(하이/로우)를 **MCU가 직접** 제어하는 드라이버(예: DRV8301, 개별 MOSFET 하프브릿지)에서 필요한 기능.
- 우리 구성(3-PWM 드라이버)에선 쓸 일이 없다.

### 3. LEDC로 성능 충분
- 짐벌 모터(2804) FOC는 스위칭 20kHz, 12bit 해상도로 충분.
- `80MHz / 4096 ≈ 19.5kHz` — 12bit에서 낼 수 있는 최대 주파수와 딱 맞음.
- 가청(~20kHz) 위라 모터 소음도 안 들림.

### 4. 구현이 단순
- LEDC = 타이머 1개 + 채널 3개 등록이 끝.
- 3채널이 같은 타이머를 공유해 위상 동기.

## 결론

**3-PWM 드라이버(SimpleFOC Mini)를 쓰므로 데드타임/상보출력이 필요 없고, LEDC의 단순함이 이득.**
MCPWM은 게이트를 직접 6개 제어하는 구성으로 갈 때 재검토.

## 참고
- 구현: `components/foc/foc.c` (`foc_init` LEDC 3채널 설정)
- LEDC ≠ LED 전용. duty 조절 가능한 범용 PWM 발생기.

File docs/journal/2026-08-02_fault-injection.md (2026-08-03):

# 2026-08-02 : 대시보드에서 센서 결함 주입

> **상태: 구현·빌드 완료.**

센서 3개를 서로 비교해 이상한 값을 골라내는 **voting**(다수결) 을 앞서 넣었다. 그런데
**그게 실제로 동작하는지 확인할 방법이 없었다.** 센서는 멀쩡하니 걸러낼 이상값이 안 생긴다.

확인하려면 고장을 만들어야 한다. 선을 뽑거나 센서를 물리적으로 건드리는 방법도 있지만,
매번 손이 가고 같은 조건을 다시 만들 수 없다. 그래서 **소프트웨어로 고장을 흉내내는 기능**을
대시보드에 넣었다.

---

## 1. 어디에 주입할까 — 이게 핵심이다

주입 지점을 잘못 잡으면 검증이 통째로 무의미해진다.

- **A안 판정 직전에 값을 바꾼다:** voting 에 들어가는 비교값만 조작한다.
- **B안 센서를 읽은 직후에 원본을 덮는다(채택):** 실제 고장과 똑같은 경로를 타게 한다.

**B안을 택했다.** A안이면 주입한 값이 voting 만 통과하고, 그 뒤에 오는 영점 빼기·범위
자르기 같은 처리는 건너뛴다. 그러면 "우리가 만든 가짜 고장" 은 걸러내는데 "진짜 고장" 은
못 거르는 상태를 못 잡아낸다. 검증하려는 대상이 판정 로직 하나가 아니라 **읽기부터 판정까지의
경로 전체**이므로, 최대한 앞에서 덮어야 한다.

---

## 2. 세 가지 고장 모드

실제로 일어나는 고장을 흉내내야 의미가 있다.

| 모드 | 흉내내는 상황 | 구현 |
|---|---|---|
| 누락 (`dropout`) | 선이 빠지거나 통신이 끊긴 상태 | 값을 전부 0 으로 하고 읽기 실패로 표시 |
| 값 고정 (`freeze`) | 센서가 멈춰 같은 값만 계속 뱉는 상태 | 마지막 정상값을 계속 되돌려 준다 |
| 점진적 변형 (`drift`) | 센서가 서서히 틀어지는 상태 | 시간에 비례해 값을 조금씩 벌린다 |

**값 고정이 가장 까다로운 고장이다.** 로봇이 가만히 있는 동안에는 정상값도 안 변하므로
멈춘 센서와 구분이 안 된다. 움직여야 비로소 드러난다. 이건 구현의 한계가 아니라 이 고장의
성질이라 대시보드에도 그렇게 적어 두었다.

### 점진적 변형의 속도는 임계값의 배수로 받는다

"초당 몇 LSB 씩 벌어지게 할까" 를 절대값으로 받으면 안 된다. 이상치 판정 임계값이 신호마다
다르기 때문이다 — 가속도는 1500, 자이로는 300 이다. 절대값으로 주면 같은 숫자인데 자이로만
먼저 걸리고 가속도는 한참 멀쩡하다.

그래서 **"초당 임계값의 몇 배로 벌어지는가"** 로 받는다. 1.0 을 넣으면 두 신호가 각자의
임계값에 맞춰 벌어져 대략 같이 걸린다.

---

## 3. 값 고정이 아무 효과가 없던 버그

만들어 놓고 걸어 봤는데 **아무 일도 안 일어났다.** 판정은 계속 정상이었다.

원인은 마지막 정상값을 저장하는 코드에 있었다.

```
읽기 성공 → held 에 현재값 저장
주입이 freeze → held 를 되돌려 줌
```

두 줄이 매 루프 순서대로 돌았다. 그러니 **방금 저장한 현재값을 그대로 돌려받는다.** 값이
고정되기는커녕 아무것도 안 하는 것과 같았다.

고친 방법은 한 줄이다. **주입이 걸려 있는 동안에는 `held` 를 갱신하지 않는다.** 그래야 주입을
건 순간의 값이 그대로 얼어붙는다.

이 버그가 조용했던 이유가 남길 만하다. 기능이 죽었는데 **에러도 경고도 안 났다.** 화면에는
"값 고정 중" 이라고 정상 표시됐다. 주입 기능 자체가 검증 도구라, 이게 조용히 망가지면
"voting 이 잘 동작한다" 는 잘못된 확신만 남는다.

---

## 4. 서버는 상태를 들지 않는다

결함 주입 명령은 브라우저 → 서버 → 로봇으로 흐른다. 서버가 중간에서 뭘 해야 할까.

**결함만 서버가 기억하고, 나머지 명령은 그대로 흘려보낸다.** 결함은 로봇이 연결돼 있지 않을
때 더미 데이터 생성기가 대신 읽어 화면을 채워야 해서 서버가 알아야 한다. 반면 그 밖의
명령은 로봇에게만 의미가 있으므로 서버가 들고 있을 이유가 없다.

이걸 나누느라 `CommandRelay` 에 `forward()` 를 따로 뒀다. 상태를 드는 경로(`apply`)와
흘리는 경로(`forward`)를 분리한 것이다.

---

## 5. 이상 이력 표

판정 결과는 초당 50번 갱신되므로 눈으로 좇을 수 없다. 이상이 스쳐 지나가면 못 본다.

그래서 **이상이 생긴 구간을 한 줄로 묶어 표에 쌓는다.** 매 프레임을 쌓으면 순식간에 수천 줄이
되므로, 같은 상태가 이어지는 동안은 한 줄로 두고 지속 시간만 늘린다. 여기서는 이 한 줄을
**에피소드**라 부른다.

표에는 시각, 판정, 배제된 채널, 오류값, 정상값, 벌어진 폭, 지속 시간이 들어간다. 가속도와
자이로는 탭으로 나누고 채널 필터도 뒀다.

---

## 결과

- ESP-IDF 빌드·서버 빌드 통과
- 대시보드에서 채널별로 세 가지 고장을 걸고 풀 수 있다
- voting 이 실제로 이상 센서를 배제하는지 눈으로 확인 가능해졌다

## 남은 일

- 실기에서 세 모드를 차례로 걸어 판정이 예상대로 바뀌는지 확인

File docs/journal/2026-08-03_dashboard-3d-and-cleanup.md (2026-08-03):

# 2026-08-03 : 대시보드 3D 자세 뷰, 그리고 코드 완성본 정리

> **상태: 3D 뷰 동작 확인. 코드 정리 후 빌드 통과.**

---

## 1. 3D 자세 뷰

대시보드에 로봇의 현재 자세를 3D 로 띄웠다. 디버깅보다는 **보여주기 목적**이다.

### 필요한 데이터는 이미 오고 있었다

펌웨어도 서버도 고칠 필요가 없었다. 대시보드가 받는 프레임에 이미 다 들어 있다.

| 값 | 내용 |
|---|---|
| `balance.angle` | 몸 기울기 [도], 0 = 똑바로 |
| `encoder.angle` | 휠 각도 [도] |

### 진짜 3D 자세는 만들 수 없다

물체가 어느 방향을 보고 있는지는 축 3개로 정해지는데, 이 로봇에서 측정되는 건 사실상
1개다.

- **앞뒤 기울기** — 측정된다. 제어가 쓰는 그 값이다.
- **좌우 기울기** — 가속도 3축이 있어 계산은 되지만, 반작용휠 로봇은 이 축으로 움직일 일이
  거의 없다.
- **제자리 돌기(방향)** — **측정 수단이 없다.** 중력은 "아래가 어디인가" 만 알려주므로 세 축
  중 둘까지만 고정된다. 나머지 하나를 알려면 지자기 센서가 필요한데 없고, 자이로를 적분하면
  몇 분 만에 오차가 쌓여 화면이 제멋대로 돌아간다.

그래서 정확히 말하면 "3D 공간에 로봇 모형을 놓고 **측정된 기울기와 휠 회전을 반영한다**" 다.
눈에 보이는 움직임은 두 개다. 구현의 한계가 아니라 이 로봇의 실제 자유도가 그렇다.

### 어떻게 그릴까 — CSS 냐 3D 엔진이냐

- **A안 CSS 3D 변환:** 라이브러리 없이 상자 몇 개를 회전시킨다. 30~40줄이면 된다.
- **B안 Three.js(채택):** 진짜 3D 엔진. 실물 CAD 모델을 그대로 띄울 수 있다.

자유도가 1~2개뿐이라 처음엔 A안을 권했다. **뒤집힌 이유는 실물 OBJ 모델이 있었기
때문이다**(`docs/frame/obj/`). 보여주기가 목적인데 실물과 똑같은 모형이 움직이는 것과
상자로 흉내 낸 것은 차이가 크다.

### 모델이 마침 우리가 원하는 대로 나뉘어 있었다

| | 정점 | 면 | 범위 (mm) |
|---|---|---|---|
| `Assembly.obj` | 9,126 | 18,384 | X ±86.7 / Y −100.3~73.2 / Z 0~46 |
| `wheel.obj` | 9,848 | 19,856 | X ±64 / Y ±64 / Z 0~4 |

`Assembly.obj` 안에 휠이 들어 있으면 따로 못 돌린다. **정점 수가 휠 하나보다도 적어서**
(9,126 < 9,848) 안 들어 있다는 걸 알 수 있었다.

그리고 **두 모델의 회전축이 똑같이 Z축이다.** 반작용휠은 몸이 기우는 축과 같은 축으로 도니
당연한데, 덕분에 구현이 깔끔해졌다. **몸통 그룹 안에 휠을 자식으로 넣으면** 기울기는 휠이
저절로 따라오고 휠 회전만 따로 주면 된다. 실제 물리와 같은 구조다.

회전 중심은 꼬리 끝(바닥 접점)에 뒀다. 실제로 그 점을 축으로 넘어지기 때문이다.

### glTF 로 바꿨지만 크기는 안 줄었다

OBJ 는 글자로 된 형식이라 브라우저가 읽으려면 일일이 해석해야 한다. 이진 형식인 glTF 로
바꾸면 작아지고 빨라질 거라 봤는데, **3.1MB → 2.9MB 로 거의 그대로였다.**

원인은 이 모델이 면마다 법선(면이 향하는 방향) 을 따로 갖고 있어 **정점을 공유할 수 없기**
때문이다. 면 하나당 정점 3개를 통째로 저장해야 하니 줄어들 여지가 없다.

다만 결과에는 영향이 없다. localhost 에서 받으므로 전송 시간이 사실상 0 이고, 글자 해석이
사라진 것만으로도 실제 로딩은 훨씬 빠르다. **패널을 접어 두고 펼칠 때 읽도록** 해서 첫
화면 로딩에도 얹히지 않는다.

### 부호는 실기에서 확인했다

기울기와 휠 회전 둘 다 처음에 반대로 돌았다. 화면을 보고 부호를 뒤집었다. 휠의 장착 위치도
가운데로 뒀다가 옆판 안쪽으로 옮겼다. 이런 건 계산으로 맞히려 하지 않는 편이 빠르다.

### 축과 각도 표시

수직 기준선(회색)과 로봇 축(주황)을 함께 그리고, 두 축 사이에 호를 그려 벌어진 각도를
보이게 했다. 각도 숫자는 3D 좌표를 화면 좌표로 투영해 HTML 로 띄운다 — 라이브러리를 더
넣지 않고도 확대했을 때 글자가 또렷하다.

---

## 2. 곁다리로 잡은 버그 — 지우기 버튼이 안 먹었다

시리얼 로그의 "지우기" 버튼이 눌러도 아무 일도 안 했다. 원인은 접기 패널과 관련된 코드였다.

접을 수 있는 섹션의 제목 줄에 버튼을 두면, 버튼을 눌렀을 때 섹션도 같이 접힌다. 그걸 막는
코드가 이랬다.

```js
el.onclick = (e) => e.stopPropagation();
```

**`onclick` 에 대입하면 앞서 걸어 둔 동작이 통째로 덮인다.** 지우기 버튼은 이 줄 때문에
"섹션 안 접히게 하기" 만 하는 버튼이 돼 있었다. 결함 주입의 "전체 해제" 버튼도 같은 이유로
죽어 있었다.

`addEventListener` 로 바꾸니 둘 다 살아났다. 여러 동작을 겹쳐 걸 수 있기 때문이다.

---

## 3. 코드 완성본 정리

기능이 자리를 잡았으므로 코드를 정리했다.

### 주석 350줄 → 74줄

남긴 기준은 둘뿐이다. **변수가 뭘 뜻하는지**(주로 단위), **함수가 무슨 기능인지**. 각각 한
줄이다.

지운 것은 실측 수치, 날짜, 일지 참조, 왜 그렇게 했는지의 경위, 대안 비교, 함수 안의 설명
주석이다. 이 근거들은 대부분 이미 일지에 있다 — PWM 주파수 선정(07-26, 07-27), 엔코더 손상
판정(07-27, 08-02), WiFi 송신 출력(07-30), 영점 처리(08-02).

### 디버깅용 코드와 조건부 분기 제거

| 지운 것 | 무엇이었나 |
|---|---|
| `DRIVE_MOTOR` 분기 | 0 으로 두면 드라이버를 끄고 계산만 하던 안전 스위치 |
| `USE_TELEMETRY` 분기 | 0 으로 두면 WiFi 없이 시리얼만 쓰던 스위치 |
| `balance_control` | `#if 0` 으로 막아 둔 옛 속도모드 제어 |
| `foc_closeloop_velocity` | `#if 0` 으로 막아 둔 옛 클로즈루프 속도 제어 |
| `foc_openloop_velocity` | 초기 브링업용 오픈루프 구동. 이제 안 쓴다 |
| `mpu6050_read_accel` | 가속도만 읽던 함수. 지금은 가속도+자이로를 한 번에 읽는다 |
| `encoder_get_z`, Z 인터럽트 | 한 바퀴 카운트(CPR)가 맞는지 검증하던 진단. 확정돼 역할이 끝났다 |
| 통계의 `d_max` / `d_max_span` | 엔코더 손상 조사용 계측. 원인이 밝혀져 역할이 끝났다 |
| 옛 PID 상수들 | 위 함수들이 쓰던 값 |

**`DRIVE_MOTOR` 이 사라진 건 짚어 둘 만하다.** 이 스위치는 게인이나 부호를 고친 뒤 모터를
물리기 전에 로그부터 확인하는 안전 장치였다(2026-07-28 일지의 3-A 단계). 이제 부팅하면
**항상 모터가 돈다.** 제어를 다시 손볼 일이 생기면 이 단계를 임시로 되살리는 편이 안전하다.

남긴 것도 있다.

- **엔코더 손상값을 버리는 처리**(`enc_implausible`) — 진단이 아니라 실제 보호 장치다.
  잘못된 값이 커뮤테이션을 날려 급가속시킨 적이 있다(2026-07-29)
- **손상 버린 횟수와 MPU 읽기 실패율** — 계속 봐야 하는 건강 지표다
- **결함 주입** — 검증 기능이지 디버깅 잔재가 아니다

### 결과

ESP-IDF 빌드 통과, 경고 없음. 바이너리가 약 6KB 줄었다.

---

## 남은 일

- **일지가 밀려 있던 것을 이번에 채웠다.** 결함 주입(08-02), 일어서기·스윙업(08-03), 이 글
- `V_SUPPLY` 가 실측값과 다르다. 자세한 것은 08-03 일어서기 일지 참조
- 문서·주석의 "MPU6050" → MPU6500 정정이 계속 밀려 있다

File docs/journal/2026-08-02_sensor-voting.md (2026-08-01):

# 2026-08-02 : 센서 3개 voting — 신호 단위 판정

> **상태: 구현·빌드·호스트 테스트까지. 실기 검증은 아직.**

MPU 3개를 달아 놓고 제어에는 mux 채널 하나만 쓰고 있었다. 나머지 둘은 대시보드에 숫자만
띄우는 장식이었다. 이번에 셋을 전부 제어에 넣었다.

여기서 말하는 **voting** 은 센서 여러 개의 값을 서로 비교해 이상한 값을 골라내고 나머지로
판단하는 다수결 방식이다. **mux** 는 하나의 통신선(I2C)을 여러 장치에 번갈아 붙여 주는
전환기다.

---

## 왜 필요했나

읽기가 성공했다고 나와도 값만 깨져 오는 경우가 있다. 전송 중 비트 하나가 뒤집히면 값이
2048 이나 16384 처럼 딱 2의 거듭제곱만큼 통째로 튄다. 함수 반환값은 성공이므로 통신 오류로는
안 잡히고, 그대로 각도 계산에 들어가 기울기를 밀어버린다.

**센서 한 개로는 이걸 알아낼 방법이 없다.** 값이 틀렸다는 걸 알려면 비교할 상대가 있어야
한다. 3개를 다는 이유가 여기 있다 — 여분이 아니라 상호 검증이다.

---

## 1. 어디서 투표할까 — 원시값이냐 추정각이냐

두 가지 후보가 있었다.

- **A안 원시값 단계(채택):** 센서 3개의 raw 값을 비교해 융합한 뒤, 상보필터는 하나만 돌린다.
- **B안 추정각 단계:** 센서마다 필터를 하나씩 돌려 각도 3개를 만들고 그 각도들을 비교한다.

**A안을 택한 이유 두 가지.**

첫째, **상보필터는 값을 부드럽게 만드는 장치다.** 비트 뒤집힘 같은 순간적인 튐이 필터를 한 번
통과하면 크기가 줄어들어, 정작 잡아내야 할 이상치가 임계값 아래로 숨는다. 애초에 잡으려던 게
"필터에 들어가서 각도를 밀어버리는 값" 이니 필터 **앞**에서 걸러야 맞다.

둘째, `balance_estimate_angle()` 은 상보필터 누적값을 함수 안 `static` 변수 하나로만 갖는다.
B안이면 센서 세 개가 이 값을 서로 덮어쓰므로 센서별 상태 분리부터 해야 한다. A안은 필터를
하나만 쓰므로 **이 문제가 아예 생기지 않는다.**

---

## 2. 무엇을 한 덩이로 볼까 — 센서 단위냐 신호 단위냐 ★

이번 작업의 핵심 결정이다.

- **센서 단위:** 축 하나라도 어긋나면 그 센서를 통째로 배제한다.
- **신호 단위(채택):** 가속도쌍 `(ax, ay)` 과 자이로 `gz` 를 **따로** 투표한다.

**신호 단위를 택한 이유.**

| 근거 | 내용 |
|---|---|
| 부품이 다르다 | 가속도계와 자이로는 한 칩 안의 **별개 소자**다. 실제로 한쪽만 고장난다 |
| 멀쩡한 값 낭비 | 센서 단위면 자이로 하나 어긋났다고 그 센서의 멀쩡한 가속도까지 버린다 |
| 이미 반쯤 그랬다 | 임계값이 벌써 신호별로 다르다 — 가속도 1500, 자이로 300 |
| 역할이 다르다 | 각도는 느린 보정용, 자이로는 `K2` 로 곧장 들어가는 빠른 항이다 |

**대신 `ax` 와 `ay` 는 따로 떼지 않고 한 덩이로 묶었다.** 이 둘은 `atan2(ax, ay)` 로 묶여
각도 하나를 만든다. 따로 투표하면 `ax` 는 센서 0·1 에서, `ay` 는 센서 0·2 에서 나오는 식이
되어 **어떤 센서도 실제로 본 적 없는 조합**이 만들어진다.

치르는 대가도 있다. 판정 결과가 하나에서 둘로 늘어나 텔레메트리 JSON 과 대시보드 표시가
그만큼 늘고, "몇 번 센서가 고장" 이라는 한 줄 진단이 "몇 번의 자이로가 고장" 으로 쪼개져
눈으로 훑기에 조금 덜 직관적이다. 그래도 멀쩡한 센서를 버리지 않는 쪽이 낫다고 봤다.

---

## 3. 비교하려면 먼저 영점을 맞춰야 한다

세 센서를 그냥 비교하면 안 된다. 개체차 때문에 **정상일 때도 값이 다르다.** 보정 없이
비교하면 그 개체차가 그대로 불일치로 잡혀 멀쩡한 센서가 배제된다.

자이로와 가속도를 다르게 다뤄야 했다.

| | 처리 | 이유 |
|---|---|---|
| 자이로 | 측정한 영점을 **통째로** 뺀다 | 정지 상태에서 0 이어야 하는 값이다 |
| 가속도 | 세 채널 평균의 **중앙값 대비 차이만** 뺀다 | 중력이 걸려 있다. 통째로 빼면 각도 정보까지 지워진다 |

가속도까지 통째로 뺐다면 `ay` 의 1g 성분이 사라져 기울기를 못 잰다. 지워야 하는 건 물리값이
아니라 센서 사이의 어긋남뿐이다.

이 보정이 들어가면서 `measure_gyro_bias()` 가 `measure_cal()` 로 커졌고, 이제 채널 3개를
전부 읽으므로 측정 시간이 약 1.2초에서 1.6초로 늘었다.

### 기준 각도도 같은 영점을 써야 한다

`measure_setpoint()` 은 로봇을 똑바로 세운 채 필터를 수렴시켜 "진짜 똑바로" 의 센서값을 잡는
함수다. 이 함수만 채널 0 의 날값으로 재면, 제어 루프는 중앙값 기준으로 융합한 값을 쓰는데
기준만 다른 곳을 보게 된다.

**그 차이가 수백 LSB, 각도로 1~2도다.** 각도 게인 `K1` 이 -4 V/deg 이므로 무시할 수 없어서,
`measure_setpoint()` 에도 같은 영점을 넘기도록 고쳤다.

---

## 4. 임계값은 재서 정했다

"얼마나 벌어지면 이상치인가" 를 감으로 정할 수 없어서 실측했다. 중앙값 대비 최대 편차를
정지·기울임·밸런싱 중에 각각 쟀다.

| | 정상 편차 [LSB] | 임계값 | 여유 |
|---|---|---|---|
| 가속도 | 109 ~ 490 | **1500** | 3배 |
| 자이로 | 29 ~ 150 | **300** | 2배 |

가속도 1500 이면 2048 짜리 비트 뒤집힘도 걸린다.

**여기서 임계값을 좁히고 싶은 유혹을 참아야 한다.** 세 센서는 mux 로 전환해 가며 읽으므로
서로 약 1ms 씩 어긋난 시점의 값이다. 가만히 있을 때는 문제가 안 되지만 급변 구간에서는 1ms
차이만으로도 정상값이 벌어진다. 그 폭을 재보지 않고 조이면 **외란에 반응해야 할 바로 그
순간에 FAIL 로 멈춘다.** 안전장치가 가장 필요한 순간에 꺼지는 셈이다.

---

## 5. 판정은 셋 중 하나

| | 뜻 | 동작 |
|---|---|---|
| `OK` | 3개 전부 서로 일치 | 셋 평균 |
| `DEGRADED` | 1개 배제, 나머지 둘은 일치 | 둘 평균. **여전히 상호 검증됨** |
| `FAIL` | 다수결 불가 | 값을 내지 않는다. 호출자가 직전 값 유지 |

`DEGRADED` 가 성능 저하가 아니라는 점이 중요하다. 둘이 서로 일치하는 한 검증은 계속된다.
검증이 끊기는 건 `FAIL` 뿐이다.

### 짝이 2개면 왜 FAIL 인가

서로 일치하는 짝의 개수를 세서 판정한다. 3개면 `OK`, 1개면 `DEGRADED` 다. 그런데 **2개일 때가
있다** — 0~1 은 일치, 1~2 도 일치인데 0~2 는 불일치인 사슬 모양이다.

이때 1번이 가운데에 있는 정상값인지, 아니면 0번과 2번 중 하나가 틀린 것인지 **가릴 근거가
없다.** 그래서 `FAIL` 로 둔다.

### FAIL 은 "값이 없다" 가 아니다

`FAIL` 은 "맞는지 확인할 수 없다" 는 뜻이다. 안전 필수 분야라면 여기서 안전 상태로 전환하지만,
**도립진자는 토크를 끊는 순간 넘어진다.** 그래서 `tilt`/`rate`/`uq` 를 갱신하지 않고 직전
명령을 그대로 이어간다.

특히 세 개가 전부 읽기 실패하면 값이 전부 0 인데, `atan2(0, 0)` 이 0 이라 **"똑바로 서
있다"** 로 읽힌다. 넘어지는 중에 복원 토크가 사라지는 최악의 오작동이다. 값을 그냥
흘려보내면 이 함정에 그대로 빠진다.

---

## 6. 호스트 테스트

`voting` 컴포넌트는 ESP-IDF 에 의존하지 않는 순수 C 로 짰다. 하드웨어 없이 PC 에서 바로
컴파일해 돌릴 수 있다.

```
cd esp/components/voting/test
gcc -std=c11 -Wall -Wextra -I.. test_voting.c ../voting.c -o test_voting && ./test_voting
```

9건을 덮었다 — 셋 다 일치, 하나만 튐, 사슬(짝 2개), 셋 다 어긋남, 임계값 경계, 읽기 실패
1개·2개, 안 보는 축 무시, 그리고 **자이로만 고장난 센서의 가속도가 살아남는지.** 마지막
항목이 이번 설계 결정을 그대로 검증한다.

---

## 7. 서버 계약이 바뀌었다

판정이 둘로 늘어나면서 JSON 모양이 바뀌었다.

```
이전  "voting":{"result":"ok","used":[...],"rejected":[...]}
이후  "voting":{"accel":{"result":...,"used":[...],"rejected":[...]},
                "gyro" :{"result":...,"used":[...],"rejected":[...]}}
```

`SensorFrame.Voting` 을 중첩 record 로 바꾸고 대시보드는 가속도·자이로 배지를 따로 띄운다.
`SensorFrameParseTest` 도 새 모양으로 고정했다 — 이 테스트가 깨지면 서버가 프레임을 조용히
버리고 대시보드만 멈춰서 추적이 어렵다.

---

## 결과

- ESP-IDF 빌드 통과(경고 없음), 호스트 테스트 9건 통과, 서버 테스트 4건 통과
- 제어가 이제 센서 3개를 전부 쓴다. `DEGRADED` 로도 계속 돌아간다

## 남은 일

- **실기 검증.** 부팅 직후 채널별 영점이 세 줄 찍힌다. 세 값이 크게 벌어지면 임계값 재검토 신호다
- **영점 뺀 값이 int16 범위를 넘을 수 있다.** 센서 값이 측정범위 끝(±2g, ±250도/s)에 닿은
  상태에서 영점을 더 빼면 넘어간다. 잘라 주는 처리가 아직 없다
- 대시보드에 이상 이력을 표로 표시, 대시보드에서 임의로 결함 주입 (README 결함 시뮬레이션 계획)
- 문서·주석의 "MPU6050" → MPU6500 정정

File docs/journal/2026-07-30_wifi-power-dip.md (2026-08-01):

# 2026-07-30 : 엔코더 값 손상 — 원인은 WiFi 송신 전류

> **상태: 원인 규명.** 손상의 방아쇠가 모터가 아니라 **WiFi 송신 전류**임을 확정했다.
> 완전한 해결은 [2026-08-02](2026-08-02_encoder-abz.md) — 전원 보강과 ABZ 전환.

---

## 증상

엔코더가 `raw 0` 을 반환하고 각도가 통째로 틀어진다. 그 값이 휠 속도 추정을 오염시키고,
깨진 각도로 자계를 세워 토크 방향까지 뒤집힌다.

[2026-07-27](2026-07-27_foc-noise-isolated.md) 에서 PWM 스위칭 잡음을 잡아
10kHz 로 낮췄는데도 손상이 남아 있었다. **원인이 하나가 아니었다.**

---

## 판정 : 송신 세기를 낮추자 빈도가 줄었다 ★

`esp_wifi_set_max_tx_power()` 로 송신 출력을 **20dBm → 11dBm** 으로 낮추자
손상 빈도가 눈에 띄게 줄었다.

출력을 낮추면 바뀌는 것은 **송신 순간에 끌어가는 전류**다. 통신 내용도, 버스 트래픽도,
루프 주기도 그대로다. 그 하나만 바꿔 빈도가 변했으므로 **전류가 원인**이다.

송신 순간 전류가 센서 전원을 끌어내리고, 그 전압 강하가 I2C 신호를 깨뜨린다.

공유기가 가까워(rssi −52) 11dBm 으로도 접속은 충분하다.

| 설정 | 값 |
|---|---|
| `WIFI_TX_POWER` | 44 (0.25dBm 단위 = 11dBm) |
| 기본값 | 80 (20dBm) |

---

## 소프트웨어로 걸러내려는 시도는 전부 실패했다 ★

### 1. 상한에 추정치를 쓰면 잠긴다

이상값 판정 상한을 `휠 속도 추정치 × dt` 로 잡았다. **한번 걸리면 안 풀린다.**

```
값을 버린다 → prev_angle 을 안 옮긴다 → 휠 속도 추정치가 얼어붙는다
  → 얼어붙은 값이 상한을 좁힌다 → 정상값까지 걸린다 → 다시 버린다
```

실측으로 **정상값을 13루프 연속 버렸고**, 그동안 커뮤테이션이 멈춰 급가속했다.

`2026-07-27` 에서 이미 같은 함정에 빠졌던 것의 변종이다. 그때 얻은 결론이
"상한에 추정치를 쓰지 말 것" 이었는데, 판정식을 손대면서 다시 들어갔다.

**고정 상한으로 되돌렸다.** 시간이 갈수록 상한이 넓어져 스스로 풀린다.

```c
#define ENC_MAX_VEL    80.0f    // 실측 최고 55 rad/s
#define ENC_BAD_FLOOR  0.30f
```

### 2. 루프 주기가 아니라 경과 시간으로 재야 한다

상한을 한 루프 예산으로 재면 **버린 직후의 정상값이 걸린다.** 값을 버리면 다음 값은
두 루프치 움직임을 담고 있기 때문이다. 이것도 연속 배제로 이어진다.

마지막으로 **채택한** 값 이후의 경과 시간(`since_ok`)으로 바꿨다.

### 3. 버리는 것 자체가 커뮤테이션을 멈춘다

값을 버리면 그 루프는 전압 벡터를 갱신하지 못한다. 손상이 잦으면 커뮤테이션이
자주 멈추고, 그게 다시 토크 충격을 만든다.

그래서 **버리는 대신 깎는** 경로를 더했다. 상한을 통과한 값이라도 휠 속도가 한 번에
튀지 못하게 각가속도로 제한한다. 깎는 것은 커뮤테이션을 멈추지 않는다.

```c
#define WHEEL_MAX_ACC  300.0f   // 실측 최대 약 120 rad/s²
```

---

## 곁가지 : WebSocket 연결이 굳는다

전송 도중 소켓이 사라지면 클라이언트가 `already stop` 상태로 굳어
**자동 재접속이 시작조차 안 된다.** 재접속 타이머는 클라이언트가 살아 있을 때만 돈다.

5초 넘게 연결이 안 돌아오면 클라이언트를 통째로 재시작하도록 했다.
재시작은 텔레메트리 태스크가 한다 — 이벤트 핸들러는 WS 자신의 태스크라 스스로를 못 멈춘다.

로그 전송도 고쳤다. 한 건이 실패하면 남은 것도 실패하는데, 계속 밀어넣으면
**그 실패 로그가 큐를 다시 채운다.** 첫 실패에서 중단하도록 바꿨다.

---

## 배운 것

1. **원인이 하나라고 가정하지 말 것.** PWM 잡음을 잡고도 손상이 남았다.
   같은 증상에 방아쇠가 둘이었다
2. **하나만 바꿔 빈도가 변하면 그게 원인이다.** 송신 출력은 전류만 바꾼다
3. **걸러내기는 원인을 못 고친다.** 임계값·재시도·필터를 세 번 시도해 세 번 다
   새 문제를 만들었다. `2026-07-27` 의 "우회책은 계측을 오염시킨다" 가 그대로 반복됐다
4. **버리는 것과 깎는 것은 다르다.** 버리면 커뮤테이션이 멈추고, 깎으면 안 멈춘다

---

## 남은 일

근본 원인은 **전원**이다. 소프트웨어로는 완화만 된다.
→ 전원 보강과 ABZ 전환으로 이어진다 ([2026-08-02](2026-08-02_encoder-abz.md))

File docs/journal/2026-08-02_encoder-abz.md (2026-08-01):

# 2026-08-02 : 엔코더 ABZ 전환 + 전원 보강 — 손상 해결

> **상태: 해결.** 밸런싱이 정상 동작하고 통신 오류가 사라졌다.
> 하드웨어와 소프트웨어 **양쪽을 고쳤다.**

| | 무엇 | 무엇을 해결했나 |
|---|---|---|
| 하드웨어 | 자기 인코더 전원부에 **0.1µF 세라믹 콘덴서** | 송신 전류로 생기던 전원 흔들림 |
| 소프트웨어 | 엔코더를 I2C → **ABZ (PCNT)** | I2C 버스 혼잡으로 인한 반응 지연 |

전원 문제의 원인 규명은 [2026-07-30](2026-07-30_wifi-power-dip.md) 참조.

---

## 왜 ABZ 로 옮겼나

**I2C 버스에 센서가 이미 3개다.** 여기에 엔코더까지 얹으면 한 루프에 거래가 4번이라
반응이 느려진다. 엔코더를 버스에서 빼면 그만큼 예산이 돌아온다.
PCNT 는 하드웨어가 펄스를 세므로 **읽기 대기가 0** 이다.

고장 크기도 줄어든다. I2C 는 "지금 각도" 를 통째로 받으므로 한 비트가 뒤집히면
45 / 90 / 180도가 틀어진다. ABZ 는 펄스를 세는 방식이라 하나 놓쳐도 **0.088도** 다.

대가는 **절대값 → 증분값** 이다. 부팅 시 위치를 모르므로 정렬 스윕이 기준을 잡아준다.

---

## PCNT 설계 — 회전수 누적이 필요 없다

카운터의 상·하한을 **±4096(한 바퀴)** 으로 걸면 한 바퀴마다 카운터가 스스로 0 으로
돌아간다. 그래서 **카운트가 곧 한 바퀴 안에서의 위치**가 되고, 회전수를 따로 누적하는
변수가 사라진다. 각도는 `count × 2π/4096` 한 줄로 나온다.

| 항목 | 값 |
|---|---|
| 핀 | A=21, B=22, Z=26 |
| 디코딩 | 2채널 4체배 |
| 글리치 필터 | 1µs (최고속 55rad/s 에서 펄스 간격 28µs) |

---

## 문제 1 : 카운트가 0 근처에 묶였다 ★

휠을 3바퀴 돌려도 카운트가 `-1` 과 `0` 만 오갔다.

**원인은 두 채널의 엣지 방향을 같게 건 것이었다.** 쿼드러처 4체배는 두 채널이 서로
반대 방향으로 세야 하는데, 공통 초기화 함수로 묶으면서 둘 다 같은 방향이 됐다.
A 가 센 만큼 B 가 되돌려 정확히 상쇄된다.

```c
channel_init(PIN_A, PIN_B, false);   // 상승 DECREASE / 하강 INCREASE
channel_init(PIN_B, PIN_A, true);    // 상승 INCREASE / 하강 DECREASE
```

### 진단이 결정적이었던 부분

배선과 코드 중 어느 쪽인지 못 가르고 있었다. **PCNT 를 거치지 않고 A/B 핀 전압을
직접 읽어** 제어 루프마다 바뀐 횟수를 셌다.

| 상태 | `AB변화` | 레벨 |
|---|---|---|
| 정지 | 0 | `A1 B0` 고정 |
| 회전 | 8~13 (루프 수와 비슷) | 계속 바뀜 |

**신호는 회전에만 반응했다.** 배선은 정상이고 세는 쪽이 틀렸다는 것이 한 번에 갈렸다.
이 계측이 없었으면 배선을 계속 의심했을 것이다.

---

## 문제 2 : Z 를 잡음으로 오판했다 ★

정지 상태에서 Z 인터럽트가 떠서 잡음으로 판단했다. 근거는 발생 빈도였다.

| 상태 | 구간 | Z | 간격 |
|---|---|---|---|
| 정지 | 14.3초 | 5회 | 2.9초당 1회 |
| 회전 | 7.2초 | 3회 | 2.4초당 1회 |

"돌리든 안 돌리든 비율이 같으니 회전과 무관하다" 고 결론냈다. **틀렸다.**

회전 구간에서 **실제로 몇 바퀴 돌았는지를 안 셌다.** 손으로 돌린 양이 적어 Z 가 그만큼만
뜬 것이었다. 나중에 제대로 돌리자 5.2초에 5회로 회전수와 정확히 맞았다.

정지 상태의 Z 도 설명된다. 회전자가 Z 표시 바로 위에 멈춰 있었고(Z 시점 카운트가 항상
0/1), 자기 인코더가 눈금 경계에서 한 칸씩 떨면서 Z 경계를 넘나든 것이다.

**분모를 안 맞춘 비교였다.** `2026-07-27` 에서 "루프 주기가 바뀌면 초당 몇 회는 비교가
안 된다" 로 배운 것과 같은 종류의 실수다.

---

## 한 바퀴 카운트 확정 — Z 카운트가 2784 로 고정

Z 는 한 바퀴에 정확히 같은 자리에서 나온다. 따라서 **Z 시점의 카운트가 안 밀리면
설정한 한 바퀴 값이 맞다.** 5회 모두 `2784` 였다.

넘김도 검증됐다. `4011 → 829` 는 실제로 914 카운트 진행이고,
0.104초에 914 카운트 = 2.1회전/초. 같은 줄의 `휠 12.6 rad/s`(2.0회전/초)와 맞는다.

MT6701 의 ABZ 최대 해상도가 1024PPR 이라 4096 의 배수일 가능성도 없다.

---

## 센서 축 변경

부착 방향이 바뀌어 기울기 평면이 YZ → **XY** 가 됐다.

| | 이전 | 지금 |
|---|---|---|
| 각도 | `atan2(-ay, -az)` | `atan2(ax, ay)` |
| 각속도 | `gx` | `gz` |

똑바로 선 자세에서 중력이 +Y 로 실려 `ay≈1g`, `ax≈0` 이므로 그대로 0도가 나온다.
이전 코드에 있던 `-ay, -az` 의 180도 뒤집기는 필요 없어져 뺐다.

---

## 결과

```
loop 125Hz  각도 -0.1도  각속도 0.2도/s  MPU실패 0(0.00%)  손상버림 0(raw 0)
```

| 항목 | 이전 | 지금 |
|---|---|---|
| 엔코더 값 손상 | 발생 | **0** |
| 통신 오류 | 발생 | **사라짐** |
| 밸런싱 | 불안정 | **정상** |

손상 판정 로직(`enc_implausible`, `WHEEL_MAX_ACC`)은 남겨뒀다. **`손상버림 0` 이 계속
나오는 것 자체가 전환이 성공했다는 증거**이기 때문이다.

---

## 배운 것

1. **하드웨어와 소프트웨어를 같이 봐야 한다.** 전원 흔들림은 콘덴서로, 버스 혼잡은
   구조 변경으로 잡았다. 어느 한쪽만으로는 안 끝났다
2. **신호가 없는 것과 잘못 세는 것은 다른 문제다.** 핀 전압을 직접 읽는 계측 하나가
   배선/코드를 갈랐다
3. **빈도를 비교할 때는 분모를 맞출 것.** 회전량을 안 세고 시간당 횟수만 봐서
   정상 신호를 잡음으로 판정했다
4. **기준 신호(Z)가 있으면 설정값을 검증할 수 있다.** 한 바퀴 카운트를 가정하지 않고
   실측으로 확정했다

---

## 남은 일

1. **Z 재동기화 미구현.** 지금은 Z 시점 카운트를 기록만 한다. 고속에서 펄스를 놓치면
   밀리므로 안전장치로 넣을 것. 조립이 끝나야 밀림을 측정할 수 있다
2. **3센서 voting 미구현.** 되돌려진 상태(`a0f17f9`)이고 제어는 채널 5 하나만 쓴다
3. `ENC_DIR` 은 `+1` 로 두고 있다. 오픈루프 정·역 시험으로 확인했다
4. 문서·주석의 "MPU6050" → MPU6500 정정 (WHO_AM_I `0x70`, 세 채널 모두 확인)

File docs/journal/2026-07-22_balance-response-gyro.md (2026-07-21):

# 2026-07-22 : 밸런싱 반응속도 개선 (1) — 자이로 + 상보필터 각도 추정

I2C 문제 해결 후 실기 테스트에서 드러난 "반응 지연" 문제를 추적하고,
1단계로 자이로 기반 각도 추정을 구현한 기록.

---

## 문제
- 기울어지고 ~0.1초 뒤에야 휠이 반응 → 못 잡고 넘어짐.
- (별개) target_vel/uq 양수일 때 진동·소음 — 다음 작업으로 미룸.

## 원인 (반응 지연)
전송 지연 아님(센서→구동 한 루프 10ms 내). 제어 구조·게인 문제:
1. **속도 캐스케이드** : tilt로 목표 "속도"를 정함 → 휠이 목표속도 도달하면 error→0 → uq→0 → **복원 토크 사라짐**. 밸런싱은 지속 복원 토크 필요.
2. **각속도(자이로) 미사용** : `read_accel`이 가속도만 읽고 자이로 안 읽음. 각도가 커진 뒤에야 반응 → 늦음.
3. **게인 과소** : `target_vel = 0.2·error/150`. 8° 기울어야 겨우 3V.
4. **가속도 단독** : 모터 진동·선형가속에 오염.

## 접근
- 최종은 아두이노 검증 구조(상태피드백 토크모드): `uq = K1·angle + K2·gyro (+K3·휠속도 +K4·휠위치)`.
- **Phase A** (센서 1개로 제어부터 세우기) → **Phase B** (MPU 3개 voting) 로 분리.
- Phase A 하위단계: ① 자이로 읽기 → ② 상보필터 → ③ 토크제어.

## 한 것 (① ②)

### ① 자이로 읽기
- `mpu6050_read_accel_gyro()` : 0x3B부터 14바이트 버스트(가속도6+온도2+자이로6) 한 트랜잭션.
- 자이로 기본 ±250°/s = 131 LSB/(°/s).

### tilt 축 실측
- 로봇 기울여 로그 확인 → **각도=ay, 각속도=gx**.
- 정지 시 자이로 bias(평균 offset): gx ≈ 100~130 LSB (≈1°/s). noise 아니라 bias → 시작 시 평균 빼서 보정.
  (gy≈320은 안 쓰는 축이라 무관했음.)

### ② 상보필터
- `balance_estimate_angle()`:
  - `accel_angle = atan2(-ay, -az)` [deg], `rate = (gx - gx_bias)/131` [deg/s]
  - `angle = 0.98·(angle + rate·dt) + 0.02·accel_angle`
- **wrap 문제 해결** : 똑바로 선 자세가 하필 atan2 ±180° 경계 → 제어 setpoint가 불연속점.
  `-ay,-az`로 **180° 이동** → 똑바로=0, 동작범위(±60°)가 경계에서 멀어짐. 상수 이동이라 각속도 부호 영향 없음.
- `main.c` : 시작 시 gx_bias 자동 측정(정지 200샘플 평균), 루프에서 추정 후 로그 검증.

## 검증
- 정지: angle 안정, 드리프트 없음.
- 기울이면 즉시 추종(지연 없음).
- 똑바로 → 0, 좌우 굴려도 `+60→0→-60` 연속(경계 점프 없음).
- ※ 추정 각도는 아직 **제어엔 미사용**(옛 속도제어가 모터 구동 중). 로그 검증만.

## 남은 작업
1. **③ 토크제어** : `uq = K1·angle + K2·rate` (angle=0 목표), foc에 토크 인가 함수(속도 PID 우회), K1/K2 튜닝. 부호 주의(반대면 즉시 넘어짐).
2. **Phase B** : MPU 3개 voting (센서별 bias 보정, 매 루프 3채널 read).
3. (별개) FOC 양수 uq 진동/소음.

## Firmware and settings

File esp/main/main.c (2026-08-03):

#include <math.h>
#include <string.h>
#include "freertos/FreeRTOS.h"
#include "freertos/task.h"
#include "freertos/queue.h"
#include "esp_log.h"
#include "esp_timer.h"
#include "driver/i2c.h"

#include "encoder.h"
#include "mpu6050.h"
#include "foc.h"
#include "balance.h"
#include "voting.h"
#include "telemetry.h"
#include "secrets.h"

#define I2C_PORT       I2C_NUM_0
#define PIN_SDA        16
#define PIN_SCL        17
#define I2C_FREQ_HZ    400000

#define LOOP_PERIOD_MS 8           // 제어 루프 고정 주기 [ms]
#define VEL_LPF        0.2f        // 휠 속도 LPF 계수

#define TELEMETRY_US   20000       // 대시보드 송신 간격 [µs]

#define GYRO_CAL_N     200         // gz 영점 평균 샘플 수
#define SETPOINT_MS    2000        // 상보필터를 수렴시키는 시간 [ms]

#define LAG_COMP       1.0f        // 커뮤테이션 지연 보상. 1.0 = 한 루프치

#define ALIGN_UD_V     2.0f        // 정렬에 쓰는 d축 전압 [V]
#define ALIGN_HOLD_MS  1000        // 회전자를 전기각 0 으로 끌어오는 대기 [ms]
#define ALIGN_SWEEP_MS 1000        // 한 방향 스윕 시간 [ms]
#define ALIGN_STEPS    200         // 스윕 스텝 수
#define ALIGN_SAMPLES  16          // 끝점 각도 평균 샘플 수

// 엔코더 손상 판정 상한 = ENC_MAX_VEL × 경과시간 + ENC_BAD_FLOOR [rad]
#define ENC_MAX_VEL    80.0f
#define ENC_BAD_FLOOR  0.30f

#define WHEEL_MAX_ACC  300.0f      // 휠 각가속도 상한 [rad/s^2]
#define STAT_US        100000      // 통계 창 길이 [µs]

#define CTRL_PRIO      10
#define CTRL_STACK     4096
#define CTRL_CORE      0

static const char *TAG = "MAIN";

#define NUM_SENSORS    VOTING_N
static const int MUX_CHANNELS[NUM_SENSORS] = {5, 6, 7};

#define ACC_LSB_PER_G     16384.0f  // 가속도 감도 (±2g 기준)
#define GYRO_LSB_PER_DPS  131.0f    // 자이로 감도 (±250°/s 기준)

typedef struct {
    uint32_t loops;
    uint32_t mpu_fail;
    uint32_t enc_bad;       // 잘못된 값(갑자기 튀는 값)
} stats_t;

typedef struct {
    stats_t st;
    int64_t win_us;
    float   wheel_vel;
    float   angle;      // 기울기 [deg]
    float   rate;       // 기울기 각속도 [deg/s]
    float   uq;         // q축 전압 [V]
} stats_msg_t;

static QueueHandle_t s_stats_q;

static float s_gz0[NUM_SENSORS];      // 자이로 영점
static float s_a0[NUM_SENSORS][2];    // 가속도 영점

static void i2c_bus_init(void)
{
    i2c_config_t conf = {
        .mode = I2C_MODE_MASTER,
        .sda_io_num = PIN_SDA,
        .scl_io_num = PIN_SCL,
        .sda_pullup_en = true,
        .scl_pullup_en = true,
        .master.clk_speed = I2C_FREQ_HZ,
    };
    ESP_ERROR_CHECK(i2c_param_config(I2C_PORT, &conf));
    ESP_ERROR_CHECK(i2c_driver_install(I2C_PORT, I2C_MODE_MASTER, 0, 0, 0));
}

static int16_t clamp16(float v)
{
    if (v >  32767.0f) return  32767;
    if (v < -32768.0f) return -32768;
    return (int16_t)v;
}

// 엔코더 각도 차 계산
static float angle_delta(float now, float prev)
{
    float d = now - prev;
    if (d >  (float)M_PI) d -= 2.0f * (float)M_PI;
    if (d < -(float)M_PI) d += 2.0f * (float)M_PI;
    return d;
}

// 인코더 값이 잘못되었는지 판단(갑자기 튄 값)
static bool enc_implausible(float d, float span)
{
    return fabsf(d) > ENC_MAX_VEL * span + ENC_BAD_FLOOR;
}

static void stats_print(const stats_msg_t *m)
{
    const stats_t *st = &m->st;
    unsigned long hz = m->win_us ? (unsigned long)(st->loops * 1000000LL / m->win_us) : 0;
    uint32_t reads = st->loops * NUM_SENSORS;

    ESP_LOGI(TAG, "loop %luHz  각도 %6.1f도  각속도 %7.1f도/s  uq %6.2fV  "
                  "휠 %6.1f  MPU실패 %lu(%.2f%%)  손상버림 %lu  카운트 %5d",
             hz, m->angle, m->rate, m->uq, m->wheel_vel,
             (unsigned long)st->mpu_fail,
             reads ? 100.0f * st->mpu_fail / reads : 0.0f,
             (unsigned long)st->enc_bad, encoder_get_count());
}

// 엔코더 각도 평균 구하기
static float read_angle_avg(void)
{
    float sum_s = 0.0f, sum_c = 0.0f;

    for (int i = 0; i < ALIGN_SAMPLES; i++) {
        float a;
        if (encoder_read_angle(&a) == ESP_OK) {
            sum_s += sinf(a);
            sum_c += cosf(a);
        }
        vTaskDelay(pdMS_TO_TICKS(2));
    }
    return atan2f(sum_s, sum_c);
}

// 기계각과 전기각 오프셋 구하기
static float align_rotor(void)
{
    const float step     = 2.0f * (float)M_PI / ALIGN_STEPS;
    const int   dwell_ms = ALIGN_SWEEP_MS / ALIGN_STEPS;

    foc_set_phase_voltage(ALIGN_UD_V, 0.0f, 0.0f);
    vTaskDelay(pdMS_TO_TICKS(ALIGN_HOLD_MS));

    for (int i = 1; i <= ALIGN_STEPS; i++) {
        foc_set_phase_voltage(ALIGN_UD_V, 0.0f, i * step);
        vTaskDelay(pdMS_TO_TICKS(dwell_ms));
    }
    float angle_fwd = read_angle_avg();

    for (int i = ALIGN_STEPS - 1; i >= 0; i--) {
        foc_set_phase_voltage(ALIGN_UD_V, 0.0f, i * step);
        vTaskDelay(pdMS_TO_TICKS(dwell_ms));
    }
    float angle_rev = read_angle_avg();

    foc_set_phase_voltage(0.0f, 0.0f, 0.0f);

    return foc_align(angle_fwd, angle_rev);
}

// 센서 채널별 영점
static void measure_cal(void)
{
    int32_t sg[NUM_SENSORS] = {0}, sa[NUM_SENSORS][2] = {{0}};
    int     n[NUM_SENSORS]  = {0};
    float   mean_a[NUM_SENSORS][2];
    int16_t ax, ay, az, gx, gy, gz;

    for (int i = 0; i < GYRO_CAL_N; i++) {
        for (int c = 0; c < NUM_SENSORS; c++) {
            if (mpu6050_read_accel_gyro(MUX_CHANNELS[c], &ax, &ay, &az,
                                        &gx, &gy, &gz) == ESP_OK) {
                sg[c]    += gz;
                sa[c][0] += ax;
                sa[c][1] += ay;
                n[c]++;
            }
        }
        vTaskDelay(pdMS_TO_TICKS(5));
    }

    for (int c = 0; c < NUM_SENSORS; c++) {
        s_gz0[c]     = n[c] ? (float)sg[c]    / n[c] : 0.0f;
        mean_a[c][0] = n[c] ? (float)sa[c][0] / n[c] : 0.0f;
        mean_a[c][1] = n[c] ? (float)sa[c][1] / n[c] : 0.0f;
    }

    for (int k = 0; k < 2; k++) {
        float x = mean_a[0][k], y = mean_a[1][k], z = mean_a[2][k];
        float med = (x < y) ? ((y < z) ? y : ((x < z) ? z : x))
                            : ((x < z) ? x : ((y < z) ? z : y));
        for (int c = 0; c < NUM_SENSORS; c++) s_a0[c][k] = mean_a[c][k] - med;
    }
}

// 기준 각도(세웠을 때) 도출
static float measure_setpoint(void)
{
    int64_t t0 = esp_timer_get_time(), prev = t0;
    float   angle = 0.0f, rate;
    int16_t ax, ay, az, gx, gy, gz;

    while (esp_timer_get_time() - t0 < (int64_t)SETPOINT_MS * 1000) {
        int64_t now = esp_timer_get_time();
        float   dt  = (now - prev) * 1e-6f;
        prev = now;

        if (mpu6050_read_accel_gyro(MUX_CHANNELS[0], &ax, &ay, &az,
                                    &gx, &gy, &gz) == ESP_OK) {
            angle = balance_estimate_angle((int16_t)(ax - s_a0[0][0]), (int16_t)(ay - s_a0[0][1]),
                                           gz, s_gz0[0], dt, &rate);
        }
        vTaskDelay(pdMS_TO_TICKS(LOOP_PERIOD_MS));
    }
    return angle;
}

// 대시보드로 메트리 전송
static void publish_frame(const int16_t a[][3], const int16_t g[][3],
                          const telemetry_fault_t *fault,
                          const voting_out_t *va, const voting_out_t *vg,
                          float tilt, float rate, float setpoint,
                          float uq, float enc_rad)
{
    telemetry_frame_t f = {
        .angle     = tilt,
        .rate      = rate,
        .setpoint  = setpoint,
        .uq        = uq,
        .enc_angle = enc_rad * (180.0f / (float)M_PI),
        .tol_accel = VOTING_TOL_ACC / ACC_LSB_PER_G,
        .tol_gyro  = VOTING_TOL_GYRO / GYRO_LSB_PER_DPS,
    };

    f.accel.result = (telemetry_vote_t)va->result;
    f.gyro.result  = (telemetry_vote_t)vg->result;
    f.accel.val[0] = va->val[0] / ACC_LSB_PER_G;
    f.accel.val[1] = va->val[1] / ACC_LSB_PER_G;
    f.gyro.val[0]  = vg->val[0] / GYRO_LSB_PER_DPS;
    for (int i = 0; i < NUM_SENSORS; i++) {
        f.accel.used[i] = va->used[i];
        f.gyro.used[i]  = vg->used[i];
    }

    for (int i = 0; i < NUM_SENSORS; i++) {
        f.sensors[i].ch    = MUX_CHANNELS[i];
        f.sensors[i].fault = fault[i];
        f.sensors[i].ax = (a[i][0] - s_a0[i][0]) / ACC_LSB_PER_G;
        f.sensors[i].ay = (a[i][1] - s_a0[i][1]) / ACC_LSB_PER_G;
        f.sensors[i].az =  a[i][2] / ACC_LSB_PER_G;
        f.sensors[i].gx =  g[i][0] / GYRO_LSB_PER_DPS;
        f.sensors[i].gy =  g[i][1] / GYRO_LSB_PER_DPS;
        f.sensors[i].gz = (g[i][2] - s_gz0[i]) / GYRO_LSB_PER_DPS;
        f.sensors[i].ax0 = s_a0[i][0] / ACC_LSB_PER_G;
        f.sensors[i].ay0 = s_a0[i][1] / ACC_LSB_PER_G;
        f.sensors[i].gz0 = s_gz0[i]   / GYRO_LSB_PER_DPS;
    }
    telemetry_publish(&f);
}

static void balance_loop(float offset, float setpoint)
{
    int64_t now       = esp_timer_get_time();
    int64_t prev_time = now, last_stat = now, last_pub = now;

    stats_t st = {0};
    float   wheel_vel = 0.0f, prev_angle = 0.0f;
    float   since_ok  = 0.0f;   // 마지막으로 채택한 엔코더 값 이후 경과 시간 [s]
    float   tilt = 0.0f, rate = 0.0f, uq = 0.0f;
    int16_t a[NUM_SENSORS][3], g[NUM_SENSORS][3];   // [채널][x,y,z]
    telemetry_fault_t fault[NUM_SENSORS] = {0};

    // 영점을 뺀 투표용 값 (가속도 ax,ay / 자이로 gz)
    int16_t av[NUM_SENSORS][VOTING_AXIS_MAX], gv[NUM_SENSORS][VOTING_AXIS_MAX] = {{0}};
    bool    valid[NUM_SENSORS];
    voting_out_t va = {0}, vg = {0};

    int16_t held_a[NUM_SENSORS][3] = {{0}}, held_g[NUM_SENSORS][3] = {{0}};  // freeze 가 되돌려 줄 값
    float   drift[NUM_SENSORS] = {0};                                        // drift 누적 벌어짐

    encoder_read_angle(&prev_angle);

    TickType_t last_wake = xTaskGetTickCount();

    while (1) {
        now = esp_timer_get_time();
        int64_t dt_us = now - prev_time;
        float   dt    = dt_us * 1e-6f;
        prev_time = now;
        st.loops++;

        for (int i = 0; i < NUM_SENSORS; i++) {
            float inj_rate;
            telemetry_fault_t inj = telemetry_get_inject(MUX_CHANNELS[i], &inj_rate);
            drift[i] = (inj == TELEMETRY_FAULT_DRIFT) ? drift[i] + inj_rate * dt : 0.0f;

            if (mpu6050_read_accel_gyro(MUX_CHANNELS[i],
                                        &a[i][0], &a[i][1], &a[i][2],
                                        &g[i][0], &g[i][1], &g[i][2]) != ESP_OK) {
                st.mpu_fail++;
                fault[i] = TELEMETRY_FAULT_DROPOUT;
                a[i][0] = a[i][1] = a[i][2] = 0;
                g[i][0] = g[i][1] = g[i][2] = 0;
            } else {
                fault[i] = TELEMETRY_FAULT_NONE;
                if (inj == TELEMETRY_FAULT_NONE) {
                    memcpy(held_a[i], a[i], sizeof a[i]);
                    memcpy(held_g[i], g[i], sizeof g[i]);
                }
            }

            if (inj == TELEMETRY_FAULT_DROPOUT) {
                a[i][0] = a[i][1] = a[i][2] = 0;
                g[i][0] = g[i][1] = g[i][2] = 0;
            } else if (inj == TELEMETRY_FAULT_FREEZE) {
                memcpy(a[i], held_a[i], sizeof a[i]);
                memcpy(g[i], held_g[i], sizeof g[i]);
            } else if (inj == TELEMETRY_FAULT_DRIFT) {
                a[i][0] = clamp16(a[i][0] + drift[i] * VOTING_TOL_ACC);
                a[i][1] = clamp16(a[i][1] + drift[i] * VOTING_TOL_ACC);
                g[i][2] = clamp16(g[i][2] + drift[i] * VOTING_TOL_GYRO);
            }
            if (inj != TELEMETRY_FAULT_NONE) fault[i] = inj;

            valid[i] = (fault[i] != TELEMETRY_FAULT_DROPOUT);

            av[i][0] = clamp16(a[i][0] - s_a0[i][0]);
            av[i][1] = clamp16(a[i][1] - s_a0[i][1]);
            gv[i][0] = clamp16(g[i][2] - s_gz0[i]);
        }

        voting_fuse(av, valid, 2, VOTING_TOL_ACC,  &va);
        voting_fuse(gv, valid, 1, VOTING_TOL_GYRO, &vg);

        // FAIL 이면 갱신하지 않고 직전 명령을 잇는다.
        if (va.result != VOTING_FAIL && vg.result != VOTING_FAIL) {
            tilt = balance_estimate_angle(va.val[0], va.val[1], vg.val[0],
                                          0.0f, dt, &rate) - setpoint;
            uq   = balance_torque(tilt, rate, wheel_vel);
        }

        float angle;
        encoder_read_angle(&angle);
        since_ok += dt;

        float d = angle_delta(angle, prev_angle);

        if (enc_implausible(d, since_ok)) {
            st.enc_bad++;
        } else {
            float meas = d / since_ok;
            float step = WHEEL_MAX_ACC * since_ok;
            if (meas > wheel_vel + step) meas = wheel_vel + step;
            if (meas < wheel_vel - step) meas = wheel_vel - step;

            wheel_vel  = (1.0f - VEL_LPF) * wheel_vel + VEL_LPF * meas;
            prev_angle = angle;
            since_ok   = 0.0f;

            // 읽은 위치가 아니라 다음 갱신 시점의 예상 위치에 자계를 세움.
            float adv     = LAG_COMP * wheel_vel * dt;
            float adv_max = ENC_MAX_VEL * dt;
            if (adv >  adv_max) adv =  adv_max;
            if (adv < -adv_max) adv = -adv_max;

            foc_apply_torque(uq, angle + adv, offset);
        }

        if (now - last_pub >= TELEMETRY_US) {
            last_pub = now;
            publish_frame(a, g, fault, &va, &vg, tilt, rate, setpoint, uq, prev_angle);
        }

        if (now - last_stat >= STAT_US) {
            stats_msg_t msg = { .st = st, .win_us = now - last_stat,
                                .wheel_vel = wheel_vel,
                                .angle = tilt, .rate = rate, .uq = uq };
            last_stat = now;
            xQueueOverwrite(s_stats_q, &msg);
            st = (stats_t){0};
        }

        xTaskDelayUntil(&last_wake, pdMS_TO_TICKS(LOOP_PERIOD_MS));
    }
}

static void control_task(void *arg)
{
    ESP_LOGI(TAG, "센서 영점 측정 중");
    measure_cal();

    for (int c = 0; c < NUM_SENSORS; c++) {
        ESP_LOGI(TAG, "ch%d 영점  자이로 %7.1f  가속도 %7.1f / %7.1f LSB",
                 MUX_CHANNELS[c], s_gz0[c], s_a0[c][0], s_a0[c][1]);
    }

    ESP_LOGI(TAG, "기준 각도 측정 중 (%d ms)", SETPOINT_MS);
    float setpoint = measure_setpoint();

    float offset = align_rotor();

    ESP_LOGI(TAG, "기준 각도 %.1f도", setpoint);
    balance_loop(offset, setpoint);
}

void app_main(void)
{
    static const telemetry_config_t tele_cfg = {
        .wifi_ssid     = WIFI_SSID,
        .wifi_password = WIFI_PASSWORD,
        .server_uri    = SERVER_WS_URI,
    };
    ESP_ERROR_CHECK(telemetry_start(&tele_cfg));

    i2c_bus_init();
    ESP_ERROR_CHECK(encoder_init());
    ESP_ERROR_CHECK(mpu6050_init(I2C_PORT, MUX_CHANNELS, NUM_SENSORS));

    foc_init();
    foc_enable(true);

    s_stats_q = xQueueCreate(1, sizeof(stats_msg_t));
    ESP_ERROR_CHECK(s_stats_q ? ESP_OK : ESP_ERR_NO_MEM);

    xTaskCreatePinnedToCore(control_task, "control",
                            CTRL_STACK, NULL, CTRL_PRIO, NULL, CTRL_CORE);

    stats_msg_t msg;
    while (1) {
        if (xQueueReceive(s_stats_q, &msg, portMAX_DELAY) == pdTRUE) {
            stats_print(&msg);
        }
    }
}

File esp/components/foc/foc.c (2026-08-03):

#include "foc.h"
#include <math.h>
#include "driver/ledc.h"
#include "driver/gpio.h"
#include "esp_log.h"


#define PIN_EN          5
#define PIN_IN1         18
#define PIN_IN2         19
#define PIN_IN3         23

#define PWM_FREQ_HZ     10000                   // 스위칭 주파수 [Hz]
#define PWM_RES         LEDC_TIMER_11_BIT
#define DUTY_MAX        2047                    // 11비트
#define PWM_MODE        LEDC_LOW_SPEED_MODE
#define PWM_TIMER       LEDC_TIMER_0

#define V_SUPPLY        11.6f                   // 공급 전압 [V]
#define POLE_PAIRS      7                       // 극쌍 수

static const int ch_gpio[3] = {PIN_IN1, PIN_IN2, PIN_IN3};


static float clampf(float x, float lo, float hi)
{
    if( x < lo) return lo;
    if (x > hi) return hi;
    return x;
}

// 각도를 0 ~ 2π 로 접는다.
static float normalize_angle(float a)
{
    a = fmodf(a, 2.0f * (float)M_PI);
    return (a < 0.0f) ? a + 2.0f * (float)M_PI : a;
}


void foc_init(void)
{
    gpio_config_t foc_cfg = {
        .pin_bit_mask = 1ULL << PIN_EN,
        .mode = GPIO_MODE_OUTPUT
    };
    ESP_ERROR_CHECK(gpio_config(&foc_cfg));
    ESP_ERROR_CHECK(gpio_set_level(PIN_EN, 0));

    ESP_LOGI("FOC", "EN핀 설정 완료");

    ledc_timer_config_t ledc_cfg = {
        .speed_mode = PWM_MODE,
        .duty_resolution = PWM_RES,
        .freq_hz = PWM_FREQ_HZ,
        .timer_num = PWM_TIMER,
        .clk_cfg = LEDC_AUTO_CLK
    };
    ESP_ERROR_CHECK(ledc_timer_config(&ledc_cfg));
    ESP_LOGI("FOC", "LEDC 타이머 설정 완료");


    for(int i = 0; i<3; i++){
        ledc_channel_config_t ch_cfg = {
            .gpio_num = ch_gpio[i],
            .speed_mode = PWM_MODE,
            .timer_sel = PWM_TIMER,
            .channel = LEDC_CHANNEL_0 + i,
            .duty = 0,
            .hpoint = 0
        };
        ESP_ERROR_CHECK(ledc_channel_config(&ch_cfg));
        ESP_LOGI("FOC", "3상 %d번 채널 등록 완료", i);
    }
    ESP_LOGI("FOC", "3상 채널 등록 완료");
}


void foc_enable(bool on)
{
    if(!on){
        for(int i = 0; i<3; i++){
            ledc_set_duty(PWM_MODE, LEDC_CHANNEL_0 + i, 0);
            ledc_update_duty(PWM_MODE, LEDC_CHANNEL_0 + i);
        }
        gpio_set_level(PIN_EN, 0);
    } else {
        gpio_set_level(PIN_EN, 1);
    }
}


float foc_align(float angle_fwd, float angle_rev)
{
    float a = -angle_fwd * POLE_PAIRS;
    float b = -angle_rev * POLE_PAIRS;

    float off  = atan2f(sinf(a) + sinf(b), cosf(a) + cosf(b));
    float diff = atan2f(sinf(a - b), cosf(a - b));

    ESP_LOGI("FOC", "정렬 오프셋 %.1f도 (정방향/역방향 편차 %.1f도)",
             off * 180.0f / (float)M_PI, diff * 180.0f / (float)M_PI);

    return off;
}

void foc_set_phase_voltage(float ud, float uq, float angle_el)
{
    float c = cosf(normalize_angle(angle_el));
    float s = sinf(normalize_angle(angle_el));

    // 역 Park: (d,q) → (α,β)
    float u_alpha = c * ud - s * uq;
    float u_beta  = s * ud + c * uq;

    // 역 Clarke: (α,β) → 3상
    float u[3];
    u[0] = u_alpha;
    u[1] = -0.5f * u_alpha + 0.866025f * u_beta;
    u[2] = -0.5f * u_alpha - 0.866025f * u_beta;

    for (int i = 0; i < 3; i++) {
        float dc = clampf(u[i] / V_SUPPLY + 0.5f, 0.0f, 1.0f);
        ledc_set_duty(PWM_MODE, LEDC_CHANNEL_0 + i, (uint32_t)(dc * DUTY_MAX));
        ledc_update_duty(PWM_MODE, LEDC_CHANNEL_0 + i);
    }
}

// 토크 인가: uq 를 현재 전기각에 직접 인가.
void foc_apply_torque(float uq, float now_angle, float angle_offset)
{
    uq = clampf(uq, -V_SUPPLY, V_SUPPLY);
    float angle_el = normalize_angle(now_angle * POLE_PAIRS + angle_offset);
    foc_set_phase_voltage(0.0f, uq, angle_el);
}

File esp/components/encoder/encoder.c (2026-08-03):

#include "encoder.h"
#include "driver/pulse_cnt.h"
#include "esp_check.h"
#include "esp_log.h"

#define PIN_A       21
#define PIN_B       22

#define ENC_CPR     4096        // 한 바퀴 카운트
#define ENC_DIR     (+1)        // 회전 방향 부호
#define GLITCH_NS   1000        // 이것보다 짧은 펄스는 잡음으로 처리(버림)

static const char *TAG = "ENC";

static pcnt_unit_handle_t s_unit;

static esp_err_t channel_init(int edge_gpio, int level_gpio, bool flip)
{
    pcnt_channel_handle_t ch;
    pcnt_chan_config_t cfg = {
        .edge_gpio_num  = edge_gpio,
        .level_gpio_num = level_gpio,
    };
    ESP_RETURN_ON_ERROR(pcnt_new_channel(s_unit, &cfg, &ch), TAG, "채널 생성");

    ESP_RETURN_ON_ERROR(pcnt_channel_set_edge_action(ch,
            flip ? PCNT_CHANNEL_EDGE_ACTION_INCREASE
                 : PCNT_CHANNEL_EDGE_ACTION_DECREASE,
            flip ? PCNT_CHANNEL_EDGE_ACTION_DECREASE
                 : PCNT_CHANNEL_EDGE_ACTION_INCREASE),
        TAG, "엣지 동작");

    ESP_RETURN_ON_ERROR(pcnt_channel_set_level_action(ch,
            PCNT_CHANNEL_LEVEL_ACTION_KEEP,
            PCNT_CHANNEL_LEVEL_ACTION_INVERSE),
        TAG, "레벨 동작");

    return ESP_OK;
}

esp_err_t encoder_init(void)
{
    pcnt_unit_config_t unit_cfg = {
        .high_limit =  ENC_CPR,
        .low_limit  = -ENC_CPR,
    };
    ESP_RETURN_ON_ERROR(pcnt_new_unit(&unit_cfg, &s_unit), TAG, "유닛 생성");

    pcnt_glitch_filter_config_t filter_cfg = { .max_glitch_ns = GLITCH_NS };
    ESP_RETURN_ON_ERROR(pcnt_unit_set_glitch_filter(s_unit, &filter_cfg), TAG, "필터");

    ESP_RETURN_ON_ERROR(channel_init(PIN_A, PIN_B, false), TAG, "A 채널");
    ESP_RETURN_ON_ERROR(channel_init(PIN_B, PIN_A, true),  TAG, "B 채널");

    ESP_RETURN_ON_ERROR(pcnt_unit_enable(s_unit), TAG, "enable");
    ESP_RETURN_ON_ERROR(pcnt_unit_clear_count(s_unit), TAG, "clear");
    ESP_RETURN_ON_ERROR(pcnt_unit_start(s_unit), TAG, "start");

    ESP_LOGI(TAG, "AB 엔코더 시작 (A%d B%d, %d카운트/회전)", PIN_A, PIN_B, ENC_CPR);
    return ESP_OK;
}

int encoder_get_count(void)
{
    int c = 0;
    pcnt_unit_get_count(s_unit, &c);
    return ENC_DIR * c;
}

esp_err_t encoder_read_angle(float *angle_rad)
{
    float a = encoder_get_count() * (2.0f * (float)M_PI / ENC_CPR);
    *angle_rad = (a < 0.0f) ? a + 2.0f * (float)M_PI : a;

    return ESP_OK;
}

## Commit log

2026-06-27 init: 프로젝트 개요 생성
2026-06-27 docs: 부품 목록 및 선정 근거 작성
2026-06-28 docs: 회로도 초안 작성
2026-06-28 docs: 프레임(뒷면) 모델링 추가
    [back.FCStd]
2026-06-28 docs: 프레임(전면) 모델링 추가
    [front.FCStd]
2026-06-28 docs: 프레임(모터인코더) 추가
    [encoderHolder_1.obj, encoderHolder_2.obj]
2026-06-28 docs: 프레임 설명 추가
2026-06-28 docs: 프레임(자석홀더) 추가
    [magnetHolder.obj]
2026-06-28 docs: 불필요파일 삭제
    [encoderHolder_1.obj, encoderHolder_2.obj, magnetHolder.obj]
2026-06-28 docs: 프레임(모터홀더) 추가
    [motorHolder.FCStd]
2026-06-28 docs: 프레임(모터홀더 다리) 추가
    [motorSpacer.FCStd]
2026-06-28 docs: 프레임(앞뒷면 연결부) 추가
    [spacer.FCStd]
2026-06-28 docs: 프레임(밸런싱휠) 추가
    [wheel.FCStd]
2026-06-28 docs: 프레임 종합본 추가
    [종합.FCStd]
2026-06-28 docs: 프레임 사진 추가
2026-06-28 프레임 모델링 사진 추가
2026-06-29 init: gitignore 추가
2026-06-29 docs: 프레임 앞뒷면 두께 수정
    [back.FCStd, front.FCStd]
2026-07-02 docs: 요구사항 및 개발전략 추가
2026-07-02 docs: 센서 결함 시뮬레이션 및 검증 계획 추가
2026-07-05 feat: 센서·엔코더·모터 브링업 및 작업 일지 추가
    - MPU6050 x3 (TCA9548A mux 채널 0/1/6, I2C SDA=16/SCL=17) 가속도 읽기
    - MT6701 엔코더(I2C 0x06) 각도 읽기 - IIC 솔더 점퍼 납땜 필요
    - SimpleFOC Mini + BLDC 모터 오픈루프 회전 (직접 SPWM 구현)
    - 시행착오 정리: I2C 핀, MPU 클론 WHO_AM_I, MT6701 SSI 버스 hang,
    USB 코드43, BLDCMotor 오픈루프 0V 우회
2026-07-08 docs: 디지털 트윈 계획 추가
    모바일 웹에서 로봇 자세를 실시간 3D로 확인하는 디지털 트윈 기능 계획.
    - 자세 소스는 MPU6050(가속도 센서)만 사용
    - 짐벌락 회피 위해 쿼터니언 채택
    - WebSocket 스트리밍, 별도 서버 웹(Three.js) 렌더, 기존 프레임 .obj 재사용
2026-07-10 init: 초기화
2026-07-11 delete: 불필요 파일 삭제
2026-07-11 init: 소스코드 초기화
2026-07-11 rename: 메인 소스코드 파일명 수정
    [main.c]
2026-07-13 docs: MPU6050 레지스터 맵 추가
2026-07-13 feat: MPU6050 3채널 mux 가속도 센싱 구현
2026-07-13 refactor: MPU6050 구현부 컴포넌트 분리
2026-07-14 feat: BLDC 전압모드 FOC 오픈루프 구동 구현
2026-07-14 docs: FOC 구현 일지 기록
2026-07-15 docs: 자기인코더 레지스터 맵
2026-07-15 feat: 자기 인코더 초기화 및 기능 동작 구현
2026-07-16 feat: FOC 클로즈루프 구현
2026-07-16 fix: 모터 전기각 방향에 맞도록 방향 수정
    [encoder.c]
2026-07-16 chore: 불필요 주석 삭제
2026-07-16 init: 밸런싱 로직 컴포넌트 초기화
2026-07-17 docs: 일지 추가
2026-07-18 feat: 밸런싱 제어 로직 구현
2026-07-18 feat: 메인 루프 작성(센싱, 밸런싱제어)
2026-07-18 fix: FOC uq 클램프 추가 및 속도 게인 조정
    [foc.c]
2026-07-18 wip: I2C 버스 멈춤 대응 (mux settle + 버스 복구, 진행중)
2026-07-20 fix: I2C 레거시 드라이버로 이관 (버스 stuck 워치독 리셋 해결)
    [encoder.c, main.c, mpu6050.c]
2026-07-20 docs: I2C 버스 멈춤 해결 과정 일지 추가
2026-07-21 feat: MPU6050 가속도+자이로 동시 읽기 추가
2026-07-21 feat: 상보필터 tilt 각도 추정 추가 (자이로 융합)
2026-07-21 docs: 밸런싱 반응속도 개선 일지 추가 (자이로+상보필터)
2026-07-22 perf: FreeRTOS tick 1kHz로 상향 (FOC 진동·소음 개선)
2026-07-22 fix: 인코더 각도 2바이트 단일 버스트 읽기 (일관성)
    [encoder.c]
2026-07-22 feat: 토크모드 밸런싱 제어 (상태피드백 + FOC 정렬 d축 교정)
2026-07-22 feat: 밸런스 setpoint 캘리브레이션 및 각도 데드밴드 추가
2026-07-22 docs: 밸런싱 튜닝 진행 및 드라이버 고장 상황 일지
2026-07-22 docs: 드라이버 고장 일지 사실 위주로 정정
2026-07-24 init: 서버 초기파일 추가
2026-07-24 feat: 센서 텔레메트리 기능 구현(더미테이터)
2026-07-24 feat: 센서 대시보드 추가
2026-07-25 feat: ESP32 센서 데이터 서버 실시간 송신 구현
2026-07-25 fix: 엔코더 각도 도/라디안 혼용 수정 완료
    [encoder.c]
2026-07-25 feat: ESP32 시리얼 로그 웹 대시보드 미러링 구현
2026-07-26 refactor: 프로젝트 정리 및 main.c 를 초기화만 남기고 비움
    - ESP-IDF 템플릿 잔재 제거 (.devcontainer, pytest_hello_world.py, sdkconfig.ci)
    - telemetry 를 main/ 에서 components/telemetry/ 로 분리.
    설정을 telemetry_start(&cfg) 로 주입해 component 가 secrets.h 에 의존하지 않게 함
    - README 재작성, 서버 연동 문서(docs/server.md) 추가, 작업 일지 3건 추가
    - reference/ 를 .gitignore 에 등록
    - main.c 는 I2C·엔코더·MPU·FOC 초기화만 남기고 전부 제거
    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
2026-07-26 feat: 최소 폐루프 구현 (1단계)
2026-07-26 test: 소음 원인을 I2C 버스 공유로 격리 (2단계)
2026-07-26 fix: PWM 22kHz 스위칭 잡음이 I2C 를 깨뜨리는 것을 확인, 5kHz 로 해결
    [foc.c, main.c, mpu6050.c]
2026-07-26 refactor: PWM 10kHz 확정 및 진단 코드 정리
2026-07-27 fix: 양방향 정렬과 지연 보상으로 정/역 속도 비대칭 해소
    [foc.c, main.c]
2026-07-27 docs: 정방향/역방향 속도 비대칭 일지 추가 및 원인 정정
2026-07-27 docs: 메모를 브링업 일지로 흡수하고 면접 준비 문서 제외
2026-07-27 refactor: 로그 출력 태스크 분리
2026-07-27 docs: 로그 태스크 분리 결과 일지 반영
2026-07-27 feat: 밸런싱 제어 폐루프 연결
2026-07-27 feat: 밸런싱 게인 튜닝 완료 — 자립 성공
2026-07-27 docs: 밸런싱 자립 일지 추가
2026-07-28 feat: 텔레메트리 연결 및 센서 상태 표시
2026-07-28 feat: 센서 3개 voting 추가
2026-07-28 feat: 대시보드에 voting 상태와 이상 이력 표시
2026-07-28 docs: 센서 voting 일지 추가
2026-07-28 Revert "docs: 센서 voting 일지 추가"
    This reverts commit 6238aca10ac680d17d1c4399eeee37fbced4dee1.
2026-07-28 Revert "feat: 대시보드에 voting 상태와 이상 이력 표시"
    This reverts commit 58bf6db0e562e0d4172d218f516f754e40b949bb.
2026-07-28 Revert "feat: 센서 3개 voting 추가"
    This reverts commit d5122d055bf272909ad8df02178f39b82272e872.
    [main.c]
2026-07-31 fix: WiFi 송신출력 하향과 WS 재시작으로 엔코더 손상 완화
2026-07-31 fix: 엔코더 손상값 배제와 휠 가속 상한 추가
    [main.c]
2026-07-31 feat: 엔코더를 ABZ 증분 방식으로 전환
2026-08-01 feat: 센서 부착 방향 변경에 맞춰 축을 ax/ay/gz 로 변경
2026-08-01 fix: MPU 자이로 대기 비트 해제 추가
    [mpu6050.c]
2026-08-01 docs: ABZ 전환과 전원 문제 일지 추가
2026-08-01 feat: 센서 3개 voting 을 가속도/자이로 신호 단위로 구현
2026-08-01 docs: 센서 voting 신호 단위 판정 일지 추가
2026-08-01 feat: 대시보드에 voting 이상 이력 표와 채널 카드 추가
2026-08-01 tune: 밸런싱 rate 게인을 -1.2 로 조정
2026-08-01 docs: 문서 최신화
2026-08-01 feat: 대시보드 결함 주입 추가
2026-08-01 fix: 결함 주입 값 고정이 매 루프 현재값으로 덮이던 문제 수정
    [main.c]
2026-08-03 docs: 결함 주입·일어서기·3D 뷰 일지 추가
2026-08-03 feat: 대시보드에 실물 모델 기반 3D 자세 뷰 추가
2026-08-03 fix: summary 안 버튼의 클릭 핸들러가 덮여 지우기가 동작 안 하던 문제 수정
2026-08-03 refactor: 주석을 변수·함수 설명 한 줄로 줄이고 디버깅용 분기와 미사용 코드 제거
2026-08-03 docs: 리드미 목차·순서 정리, 실물 사진과 대시보드 이미지 추가, 완료된 미결 사항 삭제
2026-08-03 fix: 모바일에서 3D 캔버스가 화면배율 배로 커져 로봇이 안 보이던 문제 수정
2026-08-03 docs: 로봇 형상 이미지 추가 및 동작 영상 링크 추가
